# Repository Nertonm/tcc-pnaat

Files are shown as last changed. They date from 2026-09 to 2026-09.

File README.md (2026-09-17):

# PNAAT: inspeção multi-view e rastreabilidade em linha de envase

Sistema de inspeção para bancada de envase de garrafas PET. O repositório contém firmware, ponte serial,
serviço de captura, gateway HTTP, inferência, registro SQLite, dashboard, cadeia de treino e CAD. A ponte
em `src-production/firmware/esp32cam-test/esp32cam_site.py` é dona das portas seriais e encaminha o trigger à câmera;
`api.py` integra as superfícies do rig e da ponte por `PNAAT_RIG` e `PNAAT_PONTE`.

O manual descreve as rotas e os contratos reais. O ponto de entrada técnico é
`docs/operacao-pipeline.md`: ele separa a ponte serial, o serviço de rig, a inferência por diretório e
a ingestão persistida. A topologia e os endereços do runtime são dados de instalação, não valores
versionados.

O núcleo não controla a velocidade da esteira, não atua sobre o item, não promete acurácia sem
medição e não aprova item com evidência ausente. Atuação física, iluminação pulsada, encoder e MQTT
com múltiplos nós são expansão (`docs/escopo.md`).

## Sumário

- [1. Artefatos da entrega](#1-artefatos-da-entrega)
- [2. Rotas de execução](#2-rotas-de-execução)
- [3. Hardware e montagem](#3-hardware-e-montagem)
- [4. Requisitos de software](#4-requisitos-de-software)
- [5. Instalação passo a passo](#5-instalação-passo-a-passo)
- [6. Operar as rotas existentes](#6-operar-as-rotas-existentes)
- [7. Dataset, modelos e CAD](#7-dataset-modelos-e-cad)
- [8. Treinar o detector do zero](#8-treinar-o-detector-do-zero)
- [9. Verificação e reprodutibilidade](#9-verificação-e-reprodutibilidade)
- [10. Estrutura do repositório](#10-estrutura-do-repositório)
- [11. Limites conhecidos](#11-limites-conhecidos)
- [12. Convenções](#12-convenções)
- [13. Créditos e licenças](#13-créditos-e-licenças)

## 1. Artefatos da entrega

| Artefato | Onde está | Estado |
|---|---|---|
| Código do produto (API, pipeline, decisão, registro, site) | `src-production/` | suíte automatizada do produto e do firmware |
| PoCs da geração anterior | fontes removidas deste checkout | os READMEs em `docs/pocs/` são histórico, não comandos executáveis |
| Cadeia de treino (dataset, treino, avaliação, calibração, pacote) | `src-production/treino/` | pronta; rodar exige GPU e o acervo externo |
| Modelos CAD do rig | `cad-produto/` | montagem conferida geometricamente, com ressalvas na seção 3 |
| Diagramas de arquitetura | `docs/arquitetura.md`, `docs/diagramas/` | proposta e implementado, lado a lado |
| Manual de replicação | este arquivo, mais `src-production/README.md` e `src-production/treino/README.md` | publicado |
| Documento formal (Levantamento de Requisitos e roteiro do pitch) | `latex-workspace/` | fonte publicada; compilar exige LuaLaTeX |
| Pacotes de modelo (7) | [huggingface.co/Nerton/pnaat-modelos](https://huggingface.co/Nerton/pnaat-modelos) | publicado, com peso, contrato e `SHA256SUMS` por pacote |
| Índice dos pesos treinados (158 pesos, 35 famílias) | `models/INDEX.csv` | índice versionado; os pesos são dado e ficam fora do repositório |
| Serviço de rig (captura de três câmeras, série e manifest) | `src-production/rig_service/` | testes com câmera falsa: 24 rotas + 49 bordas |

### 1.1 Conferência da Entrega 6

| Exigência | Evidência versionada | Como conferir |
|---|---|---|
| Código-fonte desenvolvido | `src-production/` | `make -C src-production verificar` |
| Esquemático elétrico | `docs/diagramas/interligacao-eletrica.mmd` e projeto histórico `ESP32S3-Trigger.zip` | pinagem e cautelas na seção 3.1 |
| Diagramas finais de arquitetura | `docs/arquitetura.md` | diagramas proposta e implementada, identificados separadamente |
| Pré-requisitos e recursos | seções 3 e 4 | lista de hardware, toolchains e perfis de software |
| Instalação e dependências | seção 5 | ambiente virtual ou Docker |
| Configuração | seção 5.3 | diretórios, URLs, mapa de câmeras e token |
| Montagem e ligações | seções 3.1 e 3.2 | ligação medida antes de energizar e sequência mecânica |
| Execução | seção 6 | API, inferência, ingestão e firmware |
| Confirmação do resultado | seção 9 | comandos, respostas e resultados esperados |

Esta tabela é um índice de auditoria, não substitui os procedimentos. Caminhos que dependem de
hardware ou modelos externos estão marcados como tal; a rota local sem hardware permanece executável.

## 2. Rotas de execução

O projeto tem uma arquitetura proposta e componentes de código que podem ser executados hoje. A
separação importa para replicar sem inventar integração.

```text
sensor E18 -> nó de trigger MicroPython -> ponte serial (esp32cam_site.py) -> ESP32-CAM
                            |
                  captura materializada (série do rig)
                            |
YOLO por diretório: <capturas>/<item>/<vista>.jpg -> pacote -> decisão -> SQLite

série manifestada: manifest.json + fotos -> artefato .npz legado -> decisão -> SQLite

evento de gatilho: CSV ou API -> SQLite
```

A ponte serial `esp32cam_site.py` é o consumidor do enlace UART: decodifica frames, comanda a captura
e publica o estado da ponte. O gateway `api.py` liga rig e ponte ao registro. A rota de diretório usa
pacote YOLO; a ingestão de série usa o artefato legado; as duas persistem na mesma base.

O guia com layout de arquivos, comandos, contratos, efeitos no banco e limites está em
`docs/operacao-pipeline.md`. A replicação do zero, com firmware, serviços e verificação, está em
`docs/replicacao-ponta-a-ponta.md`. A arquitetura proposta e a arquitetura implementada, separadas uma da
outra, estão em `docs/arquitetura.md`.

## 3. Hardware e montagem

A especificação completa, com números de catálogo, pinagem, montagem e o que não foi medido, está em
`docs/hardware.md`. O resumo do que a arquitetura assume:

| Componente | Papel | Estado |
|---|---|---|
| Raspberry Pi 5 | nó de visão: captura, inferência, registro e dashboard | adotado (D-19) |
| ESP32-CAM (AI-Thinker) | nó de visão: uma foto por disparo (via `CMD_TRIG`), câmera em standby entre fotos | firmware implementado e exercitado na bancada |
| Câmeras: CSI, webcam USB e ESP32-CAM | vistas do mesmo item | papéis no `mapeamento-rig.json`, que é dado da instalação |
| Sensor fotoelétrico E18-D80NK | gatilho de presença no nó MicroPython (GPIO27, active-low); a ESP32-CAM também declara GPIO13 como fonte interna | ligação elétrica não medida |
| Impressora 3D | pórtico, suportes de câmera e cases em PETG | peças em `cad-produto/` |

O mapa de câmeras para vistas é: `lateral1` vem da ESP32-CAM, `lateral2` da webcam USB e `topo` da
câmera CSI apontada para baixo (`cad-produto/00-produto/composicao-esteira/contract.json`). Trocar
esse mapa muda a decisão do item, por isso ele é declarado e não inferido.

O esquemático normativo está em `docs/diagramas/interligacao-eletrica.mmd`. O
`ESP32S3-Trigger.zip` da raiz preserva a referência histórica Wokwi, mas usa um PIR genérico e não
fecha a ligação ao GPIO27; não deve ser usado sozinho para montar a bancada.
O firmware declara o pino e o modo elétrico esperado, e o documento de hardware marca a ligação como
não validada até a medição de bancada.

O CAD está em `cad-produto/`: a montagem em `00-produto/composicao-esteira`, as 21 peças do pórtico
em `01-estrutura/`, as peças de impressão em `02-impressao/`, o inventário com SHA-256 em
`cad-produto/MANIFEST.json` e os créditos de terceiros em `cad-produto/ATRIBUICOES.md`. A conferência
foi geométrica, com resíduo de interferência não nulo nos pares da case, abaixo do limite declarado
de 0,1 mm³. Não houve cálculo estrutural, análise térmica nem liberação metrológica.

Conjectura CAD da montagem (peças referência, não desenho de fabricação):

| Imagem | O que mostra |
|---|---|
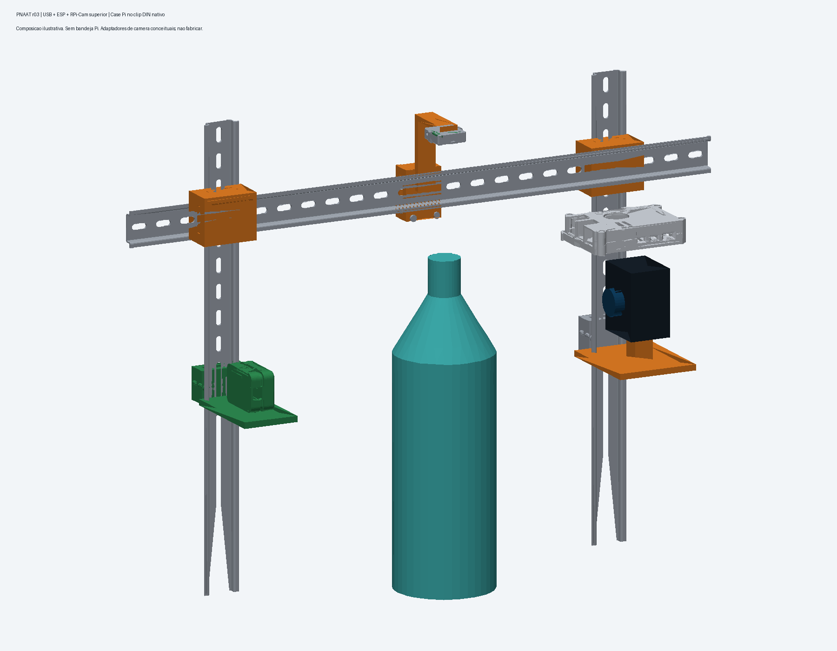
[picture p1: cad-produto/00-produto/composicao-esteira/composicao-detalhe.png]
Detalhe das câmeras e da case
|  | detalhe das três câmeras e da case da Raspberry Pi no trilho |
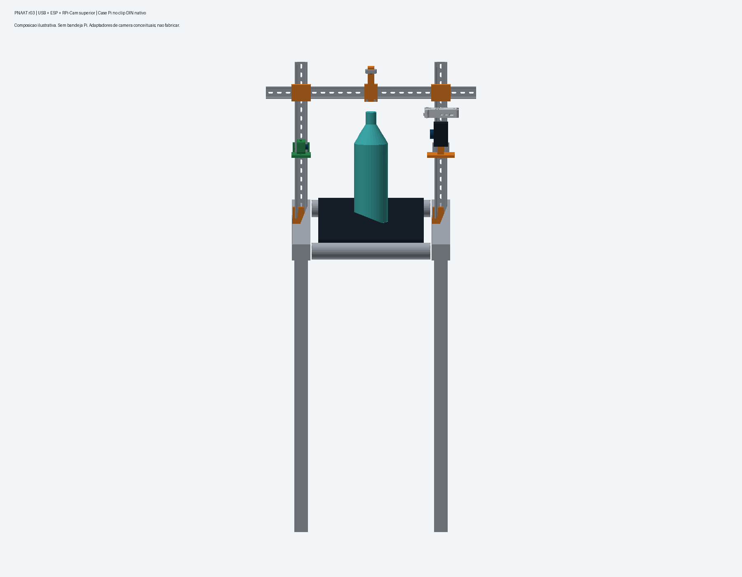
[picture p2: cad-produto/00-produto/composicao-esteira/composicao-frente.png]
Vista frontal da montagem
|  | vista frontal do conjunto |
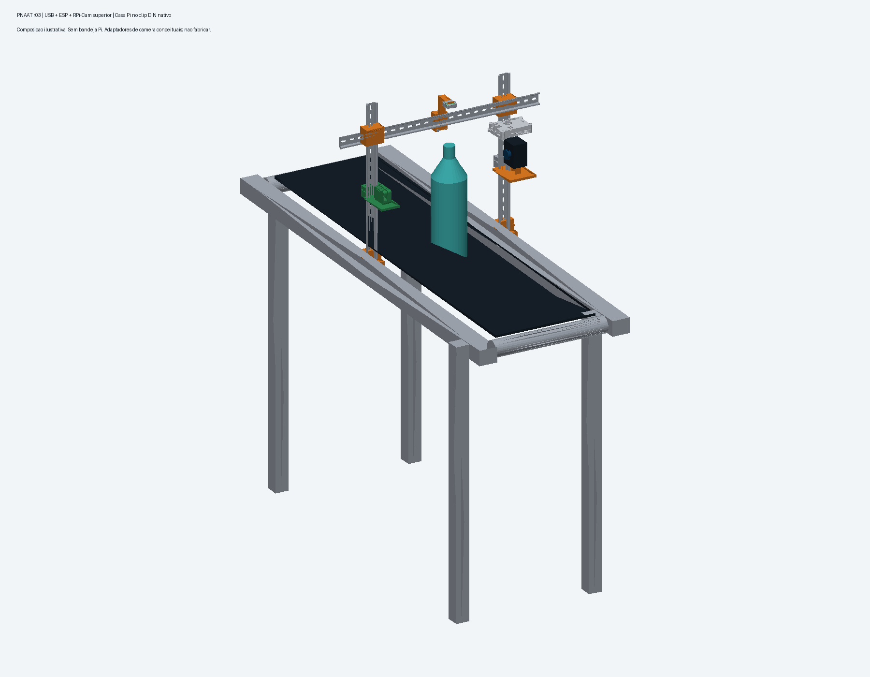
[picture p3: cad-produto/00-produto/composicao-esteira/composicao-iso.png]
Vista isolada do conjunto
|  | vista isométrica da esteira com o pórtico e as câmeras |

Os arquivos editáveis estão nos diretórios indicados
em `cad-produto/`.

### 3.1 Ligação elétrica do trigger

> **Não conecte o fio de sinal ao ESP32 antes de medir a tensão.** Desenergize a bancada para mudar
> a fiação e use GND comum. O GPIO do ESP32 aceita no máximo lógica de 3,3 V.

1. Alimente o E18-D80NK em 5 V: fio bege/marrom em `+5V` e azul em `GND`.
2. Com multímetro em tensão contínua, meça o fio preto contra GND com o sensor livre e com uma
   garrafa presente. O sinal deve ser active-low: alto em repouso e próximo de 0 V com objeto.
3. Se o sinal livre nunca passar de 3,3 V (saída open-collector pura), ligue o preto diretamente ao
   `GPIO27`; o firmware habilita o pull-up interno de 3,3 V.
4. Se o sinal livre ficar próximo de 5 V, ligue preto → `R1 2,2 kΩ` → nó do `GPIO27`, e desse nó →
   `R2 3,3 kΩ` → GND. Confirme no nó uma tensão de no máximo 3,3 V antes de conectá-lo ao GPIO.
5. `GPIO26` é apenas uma saída opcional indicadora da janela de captura; não é a ligação da
   ESP32-CAM. O trigger chega à ponte pela serial USB, e a ponte envia `CMD_TRIG` à ESP32-CAM pela
   segunda serial USB.
6. Energize e confira no monitor serial: `EV READY pin=27 out=26`, depois `EV ARMED`; uma passagem
   deve produzir exatamente um par `EV OPEN`/`EV CLOSE`.

O esquemático atualizado é `docs/diagramas/interligacao-eletrica.mmd`. O ZIP Wokwi preservado na
raiz é histórico, usa um PIR genérico e não é a fonte normativa da pinagem. Fotografias, tensão,
distância e 10 passagens com garrafa vazia e cheia devem ser registradas na validação da bancada.

### 3.2 Sequência de montagem mecânica

1. Imprima ou fabrique as peças indicadas por `cad-produto/README.md`; confira dimensões antes de
   usar os furos M6 e não trate a montagem candidata como desenho liberado para fabricação.
2. Monte `MontanteA`, `MontanteB` e `Travessa` no trilho com junções e chavetas; instale a base DIN.
3. Fixe a câmera CSI acima do trilho, eixo óptico para baixo, preservando a folga nominal de
   110,2836 mm até o topo da garrafa; valide novamente a distância para a lente realmente usada.
4. Instale ESP32-CAM e webcam USB em lados opostos, sem obstrução do item e com iluminação constante.
5. Ligue CSI ao conector da Raspberry Pi, webcam à USB e as duas ESPs a adaptadores USB-seriais
   distintos. Identifique as portas estáveis em `/dev/serial/by-id/`.
6. Declare o mapa `espcam=lateral1,usb=lateral2,csi=topo`, capture uma série de teste e confira
   visualmente se cada arquivo corresponde à vista declarada antes de habilitar decisão.

Medidas, peças, ressalvas geométricas e a lista completa de materiais estão em `docs/hardware.md`.

## 4. Requisitos de software

| Item | Uso |
|---|---|
| Python >= 3.11 e < 3.13 | produto, testes e ferramentas |
| Linux | ambiente de desenvolvimento e nó de visão |
| ESP-IDF v5.x | compilar o firmware da ESP32-CAM |
| FreeCAD com Part, Mesh e Import | reconstruir ou conferir o CAD |
| LuaLaTeX, latexmk e biber | compilar o documento formal |
| GPU com `torch` e `ultralytics` | treino e inferência YOLO; não é necessária para API e consultas locais |

`src-production/pyproject.toml` é a fonte das dependências. O runtime base declara `numpy` e
`opencv-python-headless`; os extras são `leitura` (Pillow e SciPy), `serial` (pyserial), `inferencia`
(torch, torchvision, ultralytics, scikit-learn e PyYAML) e `dev` (pytest, pytest-timeout, ruff e
PyYAML). `anomalib` não é um extra declarado neste checkout. Se for necessário para um experimento,
instale-o num ambiente separado e não o trate como pré-requisito do produto.

## 5. Instalação passo a passo

Os comandos saem da raiz do clone. Cada bloco foi rodado nesta entrega e a saída esperada está
indicada.

O Makefile raiz foi reduzido aos alvos do produto: `make install`, `make -C src-production verificar`
e `make -C src-production lint`. Para uma operação local sem
hardware, consulte `docs/operacao-pipeline.md`.

### 5.1 Obter o código

```bash
git clone https://github.com/Nertonm/tcc-pnaat.git && cd tcc-pnaat
```

### 5.2 Ambiente Python

```bash
python3.11 -m venv .venv            # ou: uv venv --seed --python 3.11 .venv
.venv/bin/python -m pip install --upgrade pip
.venv/bin/python -m pip install -e "src-production[dev,leitura,serial]"
```

O venv é único, na raiz do clone (Python >= 3.11 e < 3.13; instale `python3.11`/`python3.12` ou use
`uv`). O `Makefile` de `src-production/` encontra `../.venv/bin/python`.
Para treino e inferência YOLO, acrescente o extra de inferência:

```bash
.venv/bin/python -m pip install -e "src-production[inferencia]"
```

### 5.3 Configurar a instalação

Não há endereço, device ou mapa de câmera pessoal embutido no código. Declare, conforme a rota:

```bash
export PNAAT_SERIES_DIR=/caminho/gravavel/series
export PNAAT_PONTE=http://127.0.0.1:8094
export PNAAT_RIG=http://127.0.0.1:8090
export PNAAT_API_TOKEN='gere-um-token-longo-e-aleatorio'  # obrigatório fora de loopback/Docker
export PNAAT_MODELOS=/caminho/para/pesos-e-datasets       # somente treino/inferência
```

Use `/dev/serial/by-id/...` para `--serial` e `--serial-trigger`; não suponha que `ttyUSB0` seja
sempre a mesma placa. O diretório de séries precisa ser gravável pelo usuário do serviço. O mapa de
vistas não tem default e deve ser informado na ingestão como
`csi=topo,usb=lateral2,espcam=lateral1`. Endereços diferentes são permitidos, desde que as três URLs
sejam alcançáveis pelo gateway.

### 5.4 Verificar a instalação

```bash
make -C src-production verificar     # suíte do produto e do firmware
make -C src-production lint          # ruff com a configuração do projeto
```

A saída esperada não contém falhas, termina com `produto e firmware verificados` e o lint imprime
`All checks passed!`. Skips podem aparecer quando não estão instalados `scikit-learn`, do extra
`inferencia`, ou o artefato `.npz` do classificador, que é dado e vive fora do git. Não se fixa aqui
uma contagem: adicionar um teste correto não deve tornar o manual falso.

### 5.5 Execução conteinerizada

Como alternativa ao ambiente virtual, a composição reproduz a API, o serviço do rig e a ponte em
uma imagem Python 3.11. O perfil completo inclui a inferência e, por isso, o primeiro build pode ser
demorado. Da raiz do clone:

```bash
docker compose -f docker/docker-compose.yml build
export PNAAT_API_TOKEN='troque-este-token'
docker compose -f docker/docker-compose.yml up -d api    # sem hardware: só o núcleo
docker compose -f docker/docker-compose.yml ps
curl -H "Authorization: Bearer $PNAAT_API_TOKEN" http://127.0.0.1:8080/api/health
```

Os serviços `rig` e `ponte` precisam das câmeras e das portas seriais reais; sem o hardware, use
somente a API (`up -d api`); `rig` e `ponte` ficam no profile `hardware`. Antes de expor a porta,
defina um `PNAAT_API_TOKEN` próprio. Os devices, o diretório de séries e todas as variáveis estão documentados em `docker/docker-compose.yml` e em `docs/replicacao-ponta-a-ponta.md`.
Com hardware (câmeras e portas seriais reais), a pilha completa sobe pelo profile `hardware`:

```bash
docker compose --profile hardware -f docker/docker-compose.yml up -d
```

### 5.6 Perfis de ambiente

O runtime cobre a demonstração e a operação. O perfil completo acrescenta o que só o treino e a
detecção de anomalia usam.

| Perfil | Instalação | O que fica disponível |
|---|---|---|
| A, produto e demonstração | `src-production[dev,leitura,serial]` | cobre testes, API e demonstração local |
| B, inferência YOLO | perfil A mais `src-production[inferencia]`, pacote e dados externos | abre o pacote e roda inferência por diretório |

O `doctor` vivia na árvore de PoCs removida deste checkout. Para treino, a localização externa é
`PNAAT_MODELOS`, consumida pelo Makefile de `src-production/`; ela deve conter os datasets montados,
runs, pesos e metadados. O export canônico do Label Studio e os dados brutos não são criados pelo
clone. Veja `dataset/README.md` para a topologia do dado e `src-production/treino/README.md` para os
scripts que o consomem.

## 6. Operar as rotas existentes

O fluxo completo está em `docs/operacao-pipeline.md`. Esta seção é o resumo executável.

### 6.1 Operação local sem hardware

Sem rig, câmera e pacote, a API ainda sobe contra um banco local. Em banco novo, o
`/api/health` inicializa o schema; consulte `docs/dados-telemetria.md` para o contrato das rotas.

```bash
.venv/bin/python src-production/api.py --db hub.db --porta 8080 --host 127.0.0.1
```

Bind fora do loopback exige token. Não existe alvo de demonstração neste checkout; o site e a API
funcionam com os dados que estiverem no banco informado.

### 6.2 Inferência YOLO com imagens já materializadas

O diretório precisa ter `<CAPTURA>/<ITEM>/lateral1.jpg`, `lateral2.jpg` e `topo.jpg`. `CAPTURA` é a
pasta pai do item.

```bash
make -C src-production smoke-detector   PACOTE=/caminho/pacote-detector   CAPTURA=/caminho/capturas   ITEM=ITM-001   DB=/caminho/hub.db   JANELA=0.4   ALINHAMENTO=declarado   EQUIPAMENTO=rig   LOCALIZACAO=bancada
```

O comando valida o pacote, aplica ROI e rotação do contrato, executa a decisão e grava SQLite. Ele
escreve no banco. O classificador YOLO do pacote lateral decide tampa nas laterais; o detector de
topo existe no acervo (`*-topo-detector-roi`, `models/INDEX.csv`) e atua como check dimensional;
CORPO não tem modelo neste pacote e a conformidade mantém o item em `inconclusivo` quando a medida
é exigida.

### 6.3 Ingestão de série manifestada

```bash
.venv/bin/python src-production/ingerir_serie.py   --serie /caminho/serie --lote L1 --db /caminho/hub.db   --roi 0.0 0.0 1.0 1.0   --mapa csi=topo,usb=lateral2,espcam=lateral1   --janela-ms 2000 --alinhamento declarado
```

A série precisa de `manifest.json` e de um mapa câmera para vista. Essa rota registra evidências e usa
o artefato `.npz` legado, não `--pacote-modelo`. Para ligar o trigger físico a ela, ainda é necessário
o serviço de rig apontado por `PNAAT_RIG` (endereço e topologia são da instalação).

### 6.4 Firmware, gatilho e API

O firmware é compilado com ESP-IDF em `src-production/firmware/esp32cam-test/`. CSV e `POST
/api/gatilho` persistem eventos de gatilho, mas não acionam captura nem inferência. A API pode ser
iniciada assim:

```bash
.venv/bin/python src-production/api.py --db hub.db --porta 8080 --host 127.0.0.1
```

Bind fora do loopback exige token. Endereços de rig, ponte serial e adaptador de modelo são dados de
instalação configurados por ambiente e não entram no repositório.

## 7. Dataset, modelos e CAD

O dataset é mantido em `dataset/` e tem guia próprio em `dataset/README.md`. Ele separa captura própria,
anotação humana, dados externos, dados derivados, pares sintéticos e scripts de trabalho. O clone não
contém a entrada canônica `dataset/TRABALHO/anotacoes-ls.csv`, os exports do Label Studio, pesos `.pt`
nem o pacote do detector. Por isso um clone limpo não reproduz treino ou inferência real sem receber
esses insumos.

| Artefato externo | Consumidor | Como é declarado |
|---|---|---|
| export de anotações | `treino/monta_v1_detector.py` | `dataset/TRABALHO/anotacoes-ls.csv` |
| datasets montados, runs e pesos | Makefile de `src-production/` | `PNAAT_MODELOS` |
| pacote YOLO | `orquestracao.py` | `--pacote-modelo` ou `PACOTE=` |
| artefato legado `.npz` | `ingerir_serie.py` | `--modelo` |
| mapa câmera -> vista | ingestão de série | `--mapa` ou `--mapa-arquivo` |

`models/INDEX.csv` é um índice de pesos e hashes; ele não significa que o peso esteja no clone. O CAD
está todo em `cad-produto/`: a montagem de referência, 21 peças estruturais, peças de impressão,
contratos geométricos, `SHA256SUMS` e atribuições. Ele é uma referência geométrica ilustrativa, não
desenho liberado para fabricação. `docs/hardware.md` explica a montagem, a pinagem e o que não foi
medido.

## 8. Treinar o detector do zero

O fluxo de treino é separado da operação e está detalhado em `src-production/treino/README.md`. Ele
consome o export de anotação, monta split por item, valida listas e rótulos, treina, avalia, calibra o
limiar na validação e empacota peso, contrato e metadados. O rotulador assistido usado na criação do
dataset não participa do runtime e sua fonte foi removida
deste checkout; `docs/reference/classificar-gemini.md` preserva o registro histórico.

Com os dados externos e uma GPU disponíveis:

```bash
make -C src-production treino-dataset TAG=v10 VISTA=lateral
make -C src-production treino-run TAG=v10 VISTA=lateral EPOCHS=150 IMGSZ=480
make -C src-production treino-avalia TAG=v10 VISTA=lateral
make -C src-production treino-kfold TAG=v10 VISTA=lateral K=5
```

O pacote de entrega é o elo entre treino e inferência, e os pacotes publicados estão em
[https://huggingface.co/Nerton/pnaat-modelos](https://huggingface.co/Nerton/pnaat-modelos). O alvo `make pacote` roda em dry-run por padrão;
use `--apply` somente depois de revisar o conteúdo e apontar `PACOTE` para um diretório externo. Em
seguida, confirme o pacote já gravado:

```bash
.venv/bin/python src-production/treino/gera_contrato_preproc.py --conferir
.venv/bin/python src-production/treino/pacote_entrega.py --pacote /caminho/pacote
```

O dataset atual basta para demonstração de conceito não para afirmar desempenho operacional.

## 9. Verificação e reprodutibilidade

| Verificação | Comando | O que ela cobre |
|---|---|---|
| Produto e firmware | `make -C src-production verificar` | decisão, registro, API, cadeia, pacote, documentação e transporte; termina sem falhas |
| Lint | `make -C src-production lint` | zero achado com a configuração do `pyproject.toml` |
| Contrato do detector | `treino/gera_contrato_preproc.py --conferir` | ROI, limiares, classes, imgsz, fingerprint e SHA-256 do peso, pelo validador do consumidor |
| Pacote do detector | `treino/pacote_entrega.py --pacote <dir>` | read-back fechado de um pacote já gravado |

Nenhum número deste repositório é afirmação solta. Os pesos e o artefato do classificador são dado
com SHA-256 registrado, em `models/INDEX.csv` e em `src-production/README.md`, e cada número tem o
script que o recomputa. O caminho completo está em `src-production/README.md`, na seção "Reproduzir o
número de capa".

O que não dá para verificar sem os dados nem a instalação: acurácia do detector, medição elétrica do
sensor e desempenho no Pi 5 em operação contínua. Esses itens estão na seção 11 e em `docs/hardware.md`.

## 10. Estrutura do repositório

```text
tcc-pnaat/
├── README.md              Este manual
├── Makefile               Atalhos: install, verificar, lint
├── CONTRIBUTING.md        Convenções de contribuição e de commit
├── src-production/        O produto: API, pipeline, decisão, registro, site, firmware e treino
│   ├── treino/            Cadeia de treino, do dataset ao pacote
│   ├── firmware/          Firmware ESP32-CAM e receptor do transporte binário
│   ├── site/              Frontend estático, servido pela API
│   └── tests/             suíte automatizada do produto
├── cad-produto/           CAD do rig: montagem, 21 peças, peças de impressão, créditos e SHA256SUMS
├── docs/                  Guia de operação, arquitetura, hardware, requisitos, decisões e referências
├── dataset/               Amostras de método, 181 arquivos
├── models/                Índice dos pesos e pacotes publicados no Hugging Face
├── latex-workspace/       Documento formal e roteiro do pitch
```

A organização por namespace está descrita acima; a política de mídia e o que entra no histórico seguem o `.gitignore` e o gate de revisão do diff.

## 11. Limites conhecidos

1. O acionamento do E18-D80NK está no nó MicroPython de trigger (`src-production/firmware/trigger-node/esp/main.py`,
   GPIO27) e no contrato da ESP32-CAM (GPIO13). Níveis elétricos do sensor real não foram medidos; o
   fluxo foi exercitado por comando de bancada, simulador e portas da ponte.
2. A ponte serial em `src-production/firmware/esp32cam-test/esp32cam_site.py` recebe o trigger,
   comanda a câmera e publica o estado do enlace. O gateway `api.py` encaminha as rotas do rig e da
   ponte. Captura, ingestão e inferência usam contratos próprios; `docs/operacao-pipeline.md` descreve
   onde cada serviço entra e que dados persistem.
3. O número do modelo de tampa, 0,977 de acurácia com Wilson 0,882, vem do conjunto próprio, que
   conta as imagens de deformidade como `normal` no domínio da tampa. O mapeamento é deliberado e
   está em `src-production/README.md`.
4. O valor do limiar por classe não entra na impressão digital do contrato. Só ROI, rotação,
   orientação, imgsz, classes, vista e o SHA do peso são cobertos, então editar o número mantendo
   `fonte` e `calibrado` passa na validação estrutural. É lacuna conhecida, registrada no README do
   produto.
5. O CAD tem conferência geométrica e nada além disso: sem cálculo estrutural, térmico ou liberação
   metrológica.
6. Firmware, CAD e documento formal dependem de toolchains externas, ESP-IDF, FreeCAD e LuaLaTeX.
   Sem elas, os respectivos alvos param com erro declarado.

## 12. Convenções

Documentação e comentários em português, com nomes de código sem acento. Cada PoC tem README próprio,
e cada decisão entra em `docs/DECISIONS.md` com critério de fechamento.

A árvore de PoCs e seu gate de commit foram removidos deste checkout. Antes de publicar, rode a
validação disponível no produto e revise o diff de modo explícito:

```bash
make -C src-production verificar
make -C src-production lint
git diff --check
```

Um commit, uma intenção. Nunca `git add -A`, e mídia não entra no histórico. A evidência segue a
cadeia física, dado, modelo, teste e documentação (D-16), então número sem medição não entra no
texto.

## 13. Créditos e licenças

O CAD de terceiros tem crédito, fonte e licença por arquivo em `cad-produto/ATRIBUICOES.md`: o
Raspberry Pi 5 Din Rail, de Diyalec, em CC BY-SA; o DIN Rail Bracket for M6 Bolts, de ADSRMedia, em
CC BY-NC-SA 4.0; e o Raspberry Pi 4B case with RPi camera 2 arm, de Dominik Chuchlík, em CC BY 4.0.
Os modelos oficiais da Raspberry Pi e os desenhos mecânicos estão em
`cad-produto/03-referencias/freecad/`.

Os datasets públicos usados como apoio metodológico, MVTec e Roboflow, estão em
`docs/reference/datasets-externos-roboflow.md` e em `docs/reference/`. As referências técnicas com
grau de verificação estão em `docs/REFERENCIAS.md`.

As bibliotecas usadas são NumPy, OpenCV, SciPy, Pillow e pyserial no runtime; PyTorch, torchvision,
Ultralytics e scikit-learn no treino e na inferência; e Anomalib na camada de expansão. Cada uma
mantém a licença do próprio projeto. O documento formal está em `latex-workspace/`.

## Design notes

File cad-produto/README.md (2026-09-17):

# CAD 

Peças e montagem de referência do pórtico de inspeção multi-view de garrafas PET
do TCC. O eixo Z é a altura.

## Imagens

Detalhe das três câmeras e da case da Raspberry Pi no trilho:

Detalhe das câmeras e da case

Vista frontal:

Vista frontal da montagem

Cases de Raspberry Pi avaliadas, lado a lado:

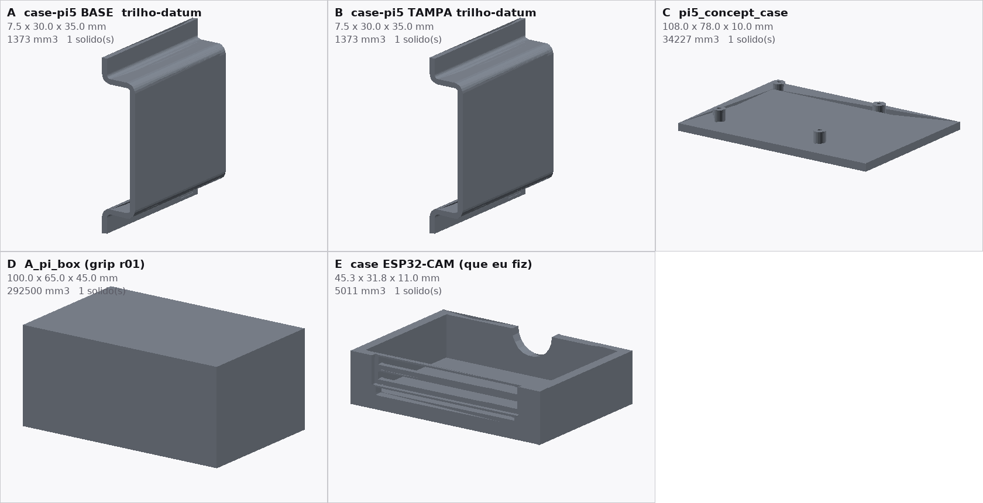
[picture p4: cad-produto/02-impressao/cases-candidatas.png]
Cases avaliadas


## O que tem na pasta

```
00-produto/            montagem e prévias
  composicao-esteira/  revisão r03: modelo, imagens, contrato e verificações
01-estrutura/          as 21 peças do pórtico, separadas
02-impressao/
  base-trilho/         base de chão do trilho
  camera-lateral/      suporte lateral da câmera
  case-esp32cam/       case da ESP32-CAM
  case-pi-din/         case da Raspberry Pi 5 para trilho DIN
03-referencias/        modelos de referência
ATRIBUICOES.md         autor, fonte e licença de cada modelo de terceiro
MANIFEST.json          inventário por arquivo, com origem, bytes e SHA-256
SHA256SUMS             conferência de integridade
```

### 00-produto

| arquivo | conteúdo |
|---|---|
| `00-produto/composicao-esteira/composicao.stl` | montagem completa, 51 corpos |
| `00-produto/composicao-esteira/composicao-iso.png` | vista geral |
| `00-produto/composicao-esteira/composicao-detalhe.png` | detalhe das câmeras e da case |
| `00-produto/composicao-esteira/composicao-frente.png` | vista frontal |
| `00-produto/composicao-esteira/contract.json` | referencial e conteúdo da montagem |
| `00-produto/composicao-esteira/build.py` | script que monta o conjunto |
| `00-produto/composicao-esteira/verify.py` | script que confere o conjunto |
| `00-produto/composicao-esteira/verification-build.json` | conferências feitas na montagem |
| `00-produto/composicao-esteira/verification-readback.json` | conferências feitas na reabertura |
| `00-produto/conjunto-portico.stl` | só a estrutura do pórtico |
| `00-produto/completo-iso.png` | cópia de `00-produto/composicao-esteira/composicao-iso.png` |
| `00-produto/completo-frente.png` | cópia de `00-produto/composicao-esteira/composicao-frente.png` |
| `00-produto/case-no-trilho-closeup.png` | cópia de `00-produto/composicao-esteira/composicao-detalhe.png` |

### 01-estrutura

As 21 peças do pórtico em `.stl`, uma por arquivo: MontanteA e MontanteB,
Travessa, JuncaoA e JuncaoB, ChavetaA e ChavetaB, A_BRACKET, B_BRACKET,
A_CLAMP, B_CLAMP, A_PECA, B_PECA, ClampFunctionalSource e ClampFunctionalSourceB,
PecaDuplaPlataformasOFICIAL e PecaDuplaPlataformasOFICIALB, ParafusoTravaH_A e
ParafusoTravaH_B, ParafusoTravaV_A e ParafusoTravaV_B.

### 02-impressao

| pasta | conteúdo |
|---|---|
| `base-trilho/` | base que recebe a peça do bracket já impressa, com furo passante para parafuso M6, em `.stl` e `.step`, mais a documentação da peça |
| `camera-lateral/` | suporte lateral em seis peças, em `.stl` e `.step`, com as duas peças de origem de terceiro marcadas no nome do arquivo |
| `case-esp32cam/` | case da ESP32-CAM para trilho DIN, em `.step` |
| `case-pi-din/` | case da Raspberry Pi 5 para trilho DIN, em `.stl`, com o desenho do autor e os arquivos de licença |
| `02-impressao/cases-candidatas.png` | comparação entre as cases avaliadas |

### 03-referencias

Modelos oficiais da Raspberry Pi e desenhos mecânicos, com README próprio na
subpasta `freecad/`.

## O que foi feito

Montagem de referência com esteira de exemplo, pórtico de dois montantes DIN,
travessa e três câmeras.

A case da Raspberry Pi entra pelo encaixe de trilho que a própria peça já tem,
sem bandeja e sem suporte extra. O encaixe foi localizado na lateral da peça de
origem e a case é posicionada com um giro de um quarto de volta em Z.

As câmeras ficaram assim: uma no topo, voltada para baixo e sobre a esteira; uma
webcam USB em uma lateral; uma ESP-CAM na lateral oposta.

As 21 peças do pórtico foram separadas em `01-estrutura/`.

A base de chão do trilho recebe a peça do bracket já impressa, leva um parafuso
passante M6 e quatro furos de fixação. A posição do furo veio da medição do
conjunto M6 em posição de uso, não de suposição.

A case da ESP32-CAM foi desenhada a partir das medidas de catálogo do módulo
AI-Thinker.

Os arquivos exportados foram reabertos e conferidos. As medidas exatas estão em
`00-produto/composicao-esteira/verification-build.json` e
`00-produto/composicao-esteira/verification-readback.json`.

## Conferências

Foram conferidos o número de corpos, sólidos e triângulos, o tamanho do conjunto,
o apontamento da câmera de topo, a folga dela até a garrafa e o encaixe da case
no trilho. Os pares testados não passaram do limite declarado de 0,1 mm³; a case tem resíduos não nulos de interferência registrados nos JSONs de verificação.

O encaixe da case foi medido com controle: empurrar a case para dentro ou para
fora faz o teste acusar colisão, e afastar a peça faz o teste acusar zero. Isso
mostra que o teste detecta penetração, e não que a case esteja travada.

As conferências são geométricas. Não cobrem carga, vibração, fadiga, retenção do
encaixe, foco, campo de visão nem impressão.

## Referências e créditos

A lista completa, com autor, fonte, licença e onde cada modelo foi usado, está
em `ATRIBUICOES.md`. Cada licença foi lida do arquivo que veio no próprio
download.

Três modelos de terceiro entraram no produto:

| modelo | autor | fonte | licença | onde |
|---|---|---|---|---|
| Raspberry Pi 5 Din Rail | Diyalec | Thingiverse 6335141 | CC BY-SA | case da Pi |
| DIN Rail Bracket for M6 Bolts | ADSRMedia | Printables 573570 | CC BY-NC-SA 4.0 | base do trilho |
| Raspberry Pi 4B case with RPi camera 2 arm | Dominik Chuchlík | Printables 301598 | CC BY 4.0 | suporte lateral |

O pórtico, os trilhos e a case da ESP32-CAM são geração própria do projeto.
Modelos oficiais da Raspberry Pi e desenhos mecânicos em `03-referencias/freecad/`,
que também descreve o que existe em `03-referencias/vendor/`.

## Observações

Este diretório não contém desenho de fabricação. A montagem serve para discutir
arquitetura e enquadramento das câmeras, e não passou por cálculo estrutural,
análise térmica ou liberação metrológica.

Os colares, braços e bandejas das câmeras são propostas conceituais, destacadas
em laranja nas prévias.

A webcam USB é genérica por decisão do projeto, para mostrar que a arquitetura
aceita câmeras diferentes. Isso não significa que qualquer webcam encaixe nem
que o software a suporte.

As montagens estão em `.stl` apenas. Os arquivos editáveis (`.step` e `.FCStd`)
não estão neste diretório.

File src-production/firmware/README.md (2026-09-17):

# Firmware do nó de visão e do nó de trigger

O produto carrega dois nós de firmware, ambos com o código no repositório:

| Nó | Caminho | Papel |
|---|---|---|
| Visão (ESP32-CAM) | `esp32cam-test/` | uma foto por trigger, câmera em standby entre fotos, transporte binário enquadrado; receptor `esp32cam_site.py` é dono único da porta serial |
| Trigger (ESP32 + E18-D80NK) | `trigger-node/` | sensor de presença com debounce, arming seguro e guarda anti-duplicação; MicroPython com lane de host |

A integração de ponta a ponta tem código nesta árvore: o sensor dispara o nó de trigger, a ponte
`esp32cam_site.py` recebe o enlace e comanda o nó de visão, e o gateway `api.py` conecta rig e ponte
ao registro. O que permanece configuração de instalação são os endereços (`PNAAT_RIG`, `PNAAT_PONTE`)
e a topologia das portas; não é código ausente.

## Objetivo do nó de visão

A ESP32-CAM deve cumprir somente estas responsabilidades:

1. observar o sensor de presença/trigger;
2. registrar o instante do disparo;
3. acordar a câmera e capturar um JPEG sob demanda;
4. entregar o JPEG e os metadados ao Pi por uma interface confiável;
5. voltar ao estado de baixo consumo após a captura.

O Pi é o dono do pipeline de visão, persistência, decisão e reação operacional. A ESP não deve
classificar defeitos nem decidir aprovação/reprovação.

## Fluxo

```text
sensor -> GPIO/IRQ -> fila FreeRTOS -> tarefa de captura
                                      |
                                      v
                              JPEG + metadados
                                      |
                                      v
                         UART/USB -> receptor no Pi
                                      |
                                      v
                 validação -> item capturado -> visão -> registro
```

A ISR deve ser mínima: timestamp, origem e envio para a fila com `xQueueSendFromISR`. Wake-up,
captura, codificação, transmissão e qualquer I/O ficam em tasks FreeRTOS. Um trigger não deve
executar lógica pesada dentro da ISR.

## Transporte implementado (v1)

Dois modos, alternáveis em runtime por `CMD_TRANSPORT TEXT|BIN`:

- `text`: linhas delimitadas com payload base64, no formato de texto legado;
- `bin`: enquadramento binário, com cabeçalho, payload e CRC por mensagem.

```text
SOF A5 5A | VER | TYPE | FLAGS | EVENT u16 | SEQ u32 | LEN u16 | CRC16(VER..LEN) | payload | CRC32(payload)
TYPE: 1=BEGIN 2=CHUNK 3=END 4=ACK 5=NACK        (tudo little-endian)
BEGIN: payload de 16 B (total_len u32, frame_crc32 u32, trigger_us i64)
CHUNK: payload de até 1024 B                    END: payload de 4 B (frame_crc32)
```

Logs ASCII convivem com as mensagens no mesmo fio: o receptor demuxa por enquadramento
(SOF + CRC16 do cabeçalho) e trata o resto como texto. Não há flag de modo no receptor.

Medido no fio, mesma placa e mesmas condições (frame de ~13 kB):

| modo | bytes na linha | fator sobre o JPEG | tempo na linha |
|---|---|---|---|
| texto base64 @ 921600 | 27.233 | 2,15x | 292 ms |
| binário @ 921600 | 14.921 | 1,13x | 191 ms |
| binário @ 1,5 Mbps | — | — | 145 ms |

Além do bloco binário, o firmware imprime `FRAME_INFO ... len= crc32=` em ASCII: o host recalcula
o CRC-32 do frame montado com `zlib` e compara. Duas implementações independentes concordando
separa erro de enlace de erro de implementação de CRC.

## Contrato congelado

```text
PROTOCOL_VERSION = 1
TRANSPORT = UART_USB (console e imagem no mesmo fio, demux por enquadramento)
TRIGGER_GPIO = 13 (E18-D80NK, active-low, borda de descida)
TRIGGER_ELECTRICAL_MODE = active-low, pull-up interno; níveis do sensor real ainda não medidos
FRAME_ENCODING = binário (texto mantido por compatibilidade)
FRAME_MAX_BYTES = 1024 B por chunk, 4096 B por mensagem, 4 MiB por frame no host
FRAME_TIMEOUT_MS = 25 s por foto no host (declarado no contrato; o enforcement de timeout ainda não está no receptor) (evento completo medido em ~1,4 s)
RETRY_POLICY = fail-closed: frame rejeitado não é publicado e o host tenta uma segunda captura
PERSISTENCE_POLICY = o host serve o último frame válido; o registro canônico é do pipeline do Pi
```

Estados observáveis no fio: `CAMERA_OFF boot=1` e `CAMERA_OFF motivo=fim_da_captura|falha_init|fim_do_teste`,
`STATUS camera=standby|ativa driver=0|1 transport=bin|text baud=`, `SENSOR_TEST pwdn=0|1 detect=`,
`FRAME_INFO`, `FRAME_END_BIN`.

## Energia da câmera

Entre fotos o firmware: desinicializa o driver, assere `PWDN` (standby do sensor), para o XCLK
(`ledc_stop` + pino em entrada com pull-down) e desliga a chave de carga quando ela existe.

Verificado funcionalmente: com `PWDN` alto o sensor **não responde** na detecção, e `STATUS`
reporta `camera=standby driver=0`. Atenção: isso é standby, não corte de 3V3; o módulo segue
alimentado. Corte real exige chave de carga no rail da câmera; o firmware já tem o caminho
pronto em `CAM_POWER_GPIO` (-1 = ausente nesta placa).

Comandos: `CMD_CAPTURE`, `CMD_STATUS`, `CMD_SENSOR` (teste A/B de energia), `CMD_TRANSPORT TEXT|BIN`,
`CMD_BAUD <n>`, `CMD_TEST_FALHA_INIT` (diagnóstico: força a próxima captura a falhar na init).

## Como o Pi recebe

O receptor do Pi deve ser uma única dona lógica da porta serial. Nenhuma thread HTTP deve escrever
diretamente na UART enquanto outra thread lê. Comandos devem entrar em uma fila de comandos, e a
thread responsável pela serial deve serializar leitura e escrita.

Máquina de estados mínima do receptor:

```text
IDLE
  -> HEADER_RECEIVED       ao receber FRAME_BEGIN válido
HEADER_RECEIVED
  -> RECEIVING              ao aceitar o primeiro chunk
  -> IDLE + erro            se header inválido ou timeout
RECEIVING
  -> COMPLETE               ao receber todos os chunks esperados e FRAME_END
  -> IDLE + erro            se seq faltar, duplicar, exceder limite ou timeout
COMPLETE
  -> VALIDATED              após tamanho, JPEG e CRC passarem
VALIDATED
  -> PUBLISHED              somente após disponibilizar uma cópia imutável ao pipeline do Pi
```

Regras obrigatórias no Pi:

1. ao receber `FRAME_BEGIN`, abandonar o frame parcialmente aberto anterior e registrar o motivo;
2. validar versão, origem permitida, `event_id`, tamanho máximo e campos numéricos;
3. aceitar chunks somente do `event_id` atual;
4. exigir sequência contígua, sem lacuna e sem duplicata;
5. aplicar timeout tanto entre chunks quanto para o frame inteiro;
6. limitar memória antes de alocar o payload anunciado;
7. decodificar base64 com validação estrita enquanto o modo texto existir;
8. verificar tamanho real, `FF D8`, `FF D9` e CRC-32 antes de publicar;
9. publicar o frame somente depois de todas as validações;
10. preservar `event_id`, origem, timestamp, métricas e motivo de falha;
11. nunca substituir silenciosamente um frame válido por um frame parcial ou antigo;
12. responder `ACK` apenas após validação e `NACK` com motivo fechado quando rejeitar (regra declarada; o receptor atual ainda não emite ACK/NACK, o descarte é pelo CRC/fechamento).

O estado `latest frame` é uma conveniência de visualização, não o registro canônico. O Pi deve
persistir ou encaminhar o evento de forma idempotente, usando `event_id` e a identidade do rig.

Receptor implementado: `esp32cam-test/transport_bin.py` (decoder + montador com os gates) e
`esp32cam-test/esp32cam_site.py` (dona única da porta, site de captura). Testes em
`esp32cam-test/tests/test_transport_bin.py`.

## Como o Pi deve reagir

Para `source=e18_d80nk` e frame validado:

1. registrar o evento de trigger, mesmo que a captura falhe;
2. associar o JPEG ao evento e gerar o `item_id` no lado do Pi;
3. verificar timestamp e janela temporal do rig;
4. validar legibilidade, resolução e enquadramento;
5. encaminhar a imagem para o pipeline de visão;
6. executar classificação por vista e fusão por domínio;
7. registrar decisão, confiança, evidências, hash do JPEG e métricas;
8. responder ao operador com `normal`, `defeito` ou `inconclusivo` conforme as regras do pipeline.

Reações fail-closed:

- trigger sem JPEG: registrar `inconclusivo` ou evento sem captura, nunca fingir normalidade;
- JPEG inválido/CRC incorreto: descartar como evidência, registrar `frame_invalido`;
- timeout: registrar `timeout_captura` com `event_id`;
- evento duplicado: não gerar segundo item; registrar duplicata;
- origem `usb_command`: aceitar somente em modo de bancada explicitamente habilitado;
- timestamp fora da janela: preservar a imagem, mas marcar `timestamp_divergente`;
- qualidade insuficiente: não enviar para decisão como se fosse evidência adequada;
- falha do modelo ou do registro: manter o evento e retornar `inconclusivo`.

## Trigger e pinos

A ESP32-CAM oferece GPIO13 active-low como fonte **local alternativa**, mas esse pino fica sem fio na
topologia adotada. O E18-D80NK liga ao nó de trigger dedicado (MicroPython), que usa
`PRESENCE_PIN = 27` e `CAPTURE_OUT_PIN = 26`; o evento segue pela serial USB até a ponte, que envia
`CMD_TRIG` à câmera. Só use divisor de nível se a saída livre do sensor for medida próxima de 5 V;
uma saída open-collector pura usa o pull-up de 3,3 V.

O sensor E18-D80NK é saída digital aberta (NPN): LOW = objeto dentro do alcance. Alimentação 5V;
verifique a tensão real na saída antes de ligar direto ao GPIO. GND comum entre sensor, ESP32 e host
é obrigatório. GPIO4 foi usado apenas num experimento de bancada e não faz parte do trigger.

## Critérios de aceite da integração

Verificados nesta bancada:

- [x] `PWDN` confirmado funcionalmente: `PWDN` alto → sensor não responde (`SENSOR_TEST pwdn=1 detect=0`);
- [x] uma foto por trigger: 3 triggers → exatamente 3 fotos; nenhuma foto em 15 s de ociosidade;
- [x] JPEG válido com tamanho, sequência e CRC conferidos (CRC do firmware x `zlib` no host = ok);
- [x] frame parcial ou corrompido nunca é publicado (CRC por mensagem, CRC do frame, tamanho e
      marcadores `FF D8`/`FF D9`); lacuna de chunk bloqueia o frame e é registrada;
- [x] standby em todos os caminhos (fim de captura, falha de init e fim do teste de energia);
- [x] timeout, duplicata e CRC inválido observáveis no host (contadores e eventos).

Pendentes:

- [ ] níveis elétricos do sensor de presença real e trigger físico medido (hoje só comando de bancada);
- [ ] debounce (50 ms) e cooldown (250 ms) medidos com o E18-D80NK;
- [ ] origem não autorizada: o firmware aceita o comando de bancada sempre; falta gate de modo;
- [ ] corrente e temperatura em idle, wake e captura (não medidos; exige instrumentação);
- [ ] o Pi registrar evento sem captura e captura sem decisão (integração com o pipeline);
- [ ] idempotência de item duplicado no registro canônico;
- [ ] canário em deployment persistente (hoje roda em sessão `tmux`, não como serviço).

## Referências do scaffold

- `esp32cam-test/main/main.c`: firmware (IRQ na fila, uma foto por trigger, standby, transporte);
- `esp32cam-test/transport_bin.py`: contrato binário e receptor (decoder + montador com gates);
- `esp32cam-test/tests/test_transport_bin.py`: testes do transporte (oráculo diferencial e gates);
- `esp32cam-test/esp32cam_site.py`: site de captura; dona única da porta serial;
- `esp32cam-test/usb_stream_bridge.py`: bridge antiga de visualização local, superada pelo site;
- componente `esp32-camera` (v2.1.7): restaurado pelo gerenciador de componentes do ESP-IDF a partir
  de `idf_component.yml` + `dependencies.lock`; nao e versionado.

## Nó de trigger (Sensor E18-D80NK + ESP32 MicroPython)

Portado do canônico para o produto em `trigger-node/`: `esp/main.py` (firmware), `presence.py`
(lógica pura testada), `host/` (supervisor da porta serial, escopo, harness, watch, esp_tool e
simulador) e `tests/test_trigger.py`.

```bash
make -C src-production test-trigger       # lógica pura (5 testes)
make -C src-production trigger-simular    # simulador do debounce básico, sem hardware
PYTHONPATH=src-production/firmware/trigger-node .venv/bin/python \
  src-production/firmware/trigger-node/host/poc01_teste.py --passagens 10 --espera 6 --separacao 3
```

Pinos adotados no `esp/main.py`: `PRESENCE_PIN = 27`, `CAPTURE_OUT_PIN = 26`. A montagem e a medição
obrigatória estão em `trigger-node/esp/README.md`. GPIO27 é a fonte normativa do código atual; isso
não equivale a afirmar que níveis e condicionamento do sensor físico já foram validados.

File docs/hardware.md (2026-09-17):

# Hardware, montagem e ligação

Manual de bancada do PNAAT. Diz o que o sistema usa, como o rig é montado, o que está ligado e
medido, o que está projetado e o que não foi medido. Cada afirmação traz a fonte no repositório; o
que não tem fonte aparece declarado como tal.

Estados usados neste documento: implementado (existe e foi exercitado), projetado (desenho aprovado,
sem bancada) e não medido (sem instrumentação no rig).

## 1. Lista de materiais

| # | Item | Especificação (fonte) | Papel no sistema | Estado |
|---|---|---|---|---|
| 1 | Raspberry Pi 5 | a instalação medida usa cartão de 119 GiB (`mmcblk0`); o repositório recomenda SSD ou NVMe para armazenamento (`docs/DECISIONS.md:1241-1247`) | nó de visão: captura, inferência, registro SQLite e dashboard | adotado (D-19) |
| 2 | ESP32-CAM | módulo AI-Thinker (`src-production/firmware/esp32cam-test/main/main.c:28`; `cad-produto/README.md:96-97`) | uma foto por disparo, câmera em standby entre fotos | implementado |
| 3 | ESP32 com MicroPython | nó de trigger separado, alimentado pelo USB do Pi (`docs/DECISIONS.md:1141`) | lê o sensor de presença e abre a janela de captura | implementado (PoC-01) |
| 4 | Sensor fotoelétrico E18-D80NK | 5 V, saída NPN, alcance de 3 a 80 cm; rótulo 5 VDC e 100 mA, fios bege, preto e azul, cerca de 5 V livre e 0 V com objeto (`docs/reference/ref-e18-d80nk-sensor.md:11-16,24-27`) | gatilho de presença do item | não medido com o sensor real |
| 5 | Adaptadores USB-serial | CP2102 ou CH340, portas resolvidas por `by-id` (`docs/DECISIONS.md:852,983,1149`) | ligam trigger e câmera ao Pi, em duas portas na mesma ponte | implementado |
| 6 | Câmeras | `topo` é a câmera CSI da Raspberry Pi apontada para baixo; `lateral1` é a ESP32-CAM; `lateral2` é a webcam USB UVC (`cad-produto/00-produto/composicao-esteira/contract.json`; `README.md:104`) | vistas do mesmo item | papéis definidos, e são dado da instalação |
| 7 | Cabo flat | FFC de 200 mm (`cad-produto/ATRIBUICOES.md:55`) | liga a câmera CSI à placa | |
| 8 | Trilho DIN e peças impressas | ver seção 3 | estrutura do rig | conferida geometricamente, com ressalvas na seção 3 |
| 9 | Encoder incremental KY-040 | candidato; não faz parte do implementado (`docs/DECISIONS.md:284,307-311`; `docs/arquitetura.md`, seção de expansões) | medição de movimento, na expansão | projetado (expansão) |
| 10 | Esteira | teto derivado de cerca de 107 mm/s, com passo de 80 mm e três vistas; o valor de operação segue a decidir e não medido (`docs/DECISIONS.md:610-616`, `docs/pocs/03-sincronizacao-fisica/CALIBRACAO-DELAY.md:60-64`) | movimento do item; o sistema não controla a esteira | fora do núcleo |
| 11 | Ferragens do trilho | furo passante Ø6,5 para M6, escareado Ø13×1,0, arruela Ø12, quatro furos Ø4,5 com rebaixo Ø9,0×5,0 (`cad-produto/02-impressao/base-trilho/README.md:12-19`) | fixação da base do trilho | medido |

As peças impressas estão em `cad-produto/02-impressao/`. A base do trilho é a única com números de
impressão publicados: um sólido, 241.237,2 mm³, 306,4 g, área de apoio de 11.952,0 mm² e envelope de
131,00 por 103,50 por 36,50 mm, dentro da K1C de 220 por 220 por 250 mm
(`cad-produto/02-impressao/base-trilho/README.md:21-22`, `DOCUMENTACAO-20260914.md:100`). O suporte
lateral da câmera tem 6 peças, o case da ESP32-CAM existe só em `.step`, sem STL
(`cad-produto/README.md:69`), e o case da Raspberry Pi 5 usa o encaixe de trilho DIN da própria
peça. Créditos e licenças de terceiros estão em `cad-produto/ATRIBUICOES.md`.

## 2. Pinagem e interfaces

Estas são as constantes de pino do firmware próprio, em
`src-production/firmware/esp32cam-test/main/main.c`:

| Sinal | Pino (GPIO) | Estado |
|---|---|---|
| Sensor de presença, `SENSOR_GPIO` | 13, active-low, borda de descida, pull-up interno (`main.c:21,702,704`) | declarado; níveis do sensor real não medidos |
| `PWDN` do sensor de imagem | 32, alto coloca o sensor em standby (`main.c:29,110,563`) | verificado na bancada |
| `XCLK` | 0, parado no standby com `ledc_stop` e pino em entrada com pull-down (`main.c:44,78-90,319`) | verificado |
| `SIOD` e `SIOC`, I²C da câmera | 26 e 27 (`main.c:45-46`) | implementado |
| `D0` a `D7`, barramento de dados | 5, 18, 19, 21, 36, 39, 34 e 35 (`main.c:47-54`) | implementado |
| `VSYNC`, `HREF` e `PCLK` | 25, 23 e 22 (`main.c:55-57`) | implementado |
| Chave de carga do rail 3V3 da câmera, `CAM_POWER_GPIO` | -1, ausente nesta placa; o firmware tem o caminho pronto (`main.c:38`) | não implementado no hardware |
| `RESET` da câmera, `CAM_PIN_RESET` | -1, não usado (`main.c:43`) | |
| Comunicação ESP32 e host | UART/USB, console e imagem no mesmo fio, demux por enquadramento com SOF `A5 5A`, CRC16 do cabeçalho e CRC32 do payload | medido no fio |
| Nó de trigger MicroPython (E18-D80NK) | `PRESENCE_PIN=27` active-low com pull-up e `CAPTURE_OUT_PIN=26`, declarados em `firmware/trigger-node/esp/main.py` | lógica implementada; ligação e níveis do sensor real a medir |

O contrato congelado em `src-production/firmware/README.md:78-88` declara apenas `TRIGGER_GPIO`, o
pino 13, e o modo elétrico esperado. Os outros pinos estão no firmware, não no contrato.

`GPIO4` não existe no firmware. Ele aparece uma vez como experimento de bancada em
`src-production/firmware/README.md:185` e não faz parte do trigger de produção.

### Ligação do sensor

O E18-D80NK é alimentado em 5 V e tem saída NPN, do tipo open-collector. A tensão de saída depende
do que existe do lado do módulo, e há dois casos documentados; o que decide entre eles é medição, não
suposição (`docs/reference/ref-e18-d80nk-sensor.md:27,45-49`):

1. Com resistor de pull-up para 5 V no módulo, a saída passa de 3,3 V e exige condicionamento de
   nível, com divisor ou transistor, antes do GPIO.
2. Sem pull-up para 5 V, a entrada pode ser ligada direto usando o `PULL_UP` interno do ESP32.

Nos dois casos, conferir a tensão de saída em bancada antes de ligar. Terra comum entre sensor,
ESP32 e host é obrigatório (`src-production/firmware/README.md:184`).

O esquemático de interligação atualizado está em `docs/diagramas/interligacao-eletrica.mmd`. O
projeto histórico `ESP32S3-Trigger.zip` usa um PIR genérico no Wokwi e **não** é a fonte normativa
da pinagem; sua limitação está registrada em `docs/reference/esquematico-trigger.md`. O firmware
declara GPIO27 e o modo elétrico. Falta medir, com o sensor real, os níveis de saída, o debounce, com
alvo de 50 ms, e o cooldown, com alvo de 250 ms (`main.c:23-24`;
`src-production/firmware/README.md:202`).

A montagem óptica do sensor segue o princípio IR difuso do E18-D80NK: posição e angulação são validadas em bancada; difusor e dois LEDs RGB de 5 mm fazem parte da iluminação de bancada (`docs/requisitos/05-hardware-ml.md:23-31`).
Uma alternativa em avaliação é o VL53L0X (`docs/DECISIONS.md:284`).

## 3. Montagem mecânica

As peças e a montagem de referência estão em `cad-produto/`, com o eixo Z como altura.

1. Pórtico: dois montantes DIN, `MontanteA` e `MontanteB`, mais `Travessa`, junções e chavetas, num
   total de 21 peças em `cad-produto/01-estrutura/` (`cad-produto/MANIFEST.json`).
2. Base do trilho, em `cad-produto/02-impressao/base-trilho/`: recebe o bracket já impresso, com furo
   passante Ø6,5 medido no conjunto em posição de uso, mais quatro furos de fixação
   (`cad-produto/02-impressao/base-trilho/README.md:12-19,24-31`).
3. Suporte lateral de câmera, em `cad-produto/02-impressao/camera-lateral/`: 6 peças em 12 arquivos
   entre `.stl` e `.step`. Três trazem marca de origem de terceiro no próprio nome
   (`Cover_SOURCE_REFERENCE`, `Housing_SOURCE_REFERENCE` e `Swivel_SOURCE_DERIVATIVE`), e
   `cad-produto/ATRIBUICOES.md:42-43` atribui quatro componentes: housing, tampa, swivel e braço.
4. Cases: `case-esp32cam`, desenhada a partir das medidas de catálogo do módulo e só em `.step`, e
   `case-pi-din`, que usa o encaixe de trilho da própria peça de origem girada um quarto de volta em
   Z. O autor e a licença estão no diretório.
5. Câmeras: uma CSI no topo apontada para baixo, uma webcam USB em uma lateral e uma ESP32-CAM na
   lateral oposta (`cad-produto/README.md:87-88`;
   `cad-produto/00-produto/composicao-esteira/contract.json`).

As conferências feitas e o que elas valem estão em
`cad-produto/00-produto/composicao-esteira/verification-build.json` e
`cad-produto/00-produto/composicao-esteira/verification-readback.json`:

| Medida | Valor |
|---|---|
| Corpos, sólidos STEP e triângulos STL | 51, 57 e 80.212 |
| Envelope do conjunto | 600,0 por 1300,0 por 1302,902 mm |
| Eixo óptico da câmera de topo | `[0, 0, -1]`, com `target_dot` de 1,0 |
| Folga do topo até o topo da garrafa | 110,2836 mm |
| Encaixe da case no trilho, controle | 98,386387 mm³ para dentro, 10,256758 mm³ para fora no gancho e 0 mm³ afastado |
| Interferência residual do par case e trilho | 0,0320589710 mm³ na base e 0,0091627391 mm³ na tampa; o limite declarado é 0,1 mm³ e nenhum par passa dele |
| Erro relativo de volume do STEP | 1,6e-10 |

O CAD não chamou esses resíduos de zero. O README do conjunto diz que eles existem e ficam abaixo do
limite declarado (`cad-produto/00-produto/composicao-esteira/README.md:15-16,27`), e o status do
conjunto é `CANDIDATE_GEOMETRY`, ilustrativo e não liberado para fabricação
(`cad-produto/00-produto/composicao-esteira/verification-build.json:2`; `cad-produto/MANIFEST.json:5`;
`cad-produto/00-produto/composicao-esteira/contract.json:10`).

O teste do encaixe tem controle: empurrar a case acusa colisão e afastar zera. Isso mostra que o teste
detecta penetração, não que a case esteja travada
(`cad-produto/00-produto/composicao-esteira/README.md:19-22`).

As pendências do CAD, registradas: o suporte da câmera de topo é conceitual e não está liberado para
imprimir (`cad-produto/00-produto/composicao-esteira/README.md:34`); PCB e lente são ilustrativos e o
CM3 Wide não foi validado
(`cad-produto/00-produto/composicao-esteira/verification-build.json:51`); a inspeção visual não foi
realizada, por falha do provedor de visão
(`cad-produto/00-produto/composicao-esteira/verification-readback.json:29`,
`cad-produto/00-produto/composicao-esteira/README.md:39`); a compatibilidade física está confirmada
pelo usuário, não medida (`cad-produto/00-produto/composicao-esteira/README.md:22`); e a licença do
modelo da ESP não foi verificada (`cad-produto/00-produto/composicao-esteira/README.md:36`;
`cad-produto/ATRIBUICOES.md:101-110`). Na base do trilho, Y igual a 0 é suposição, o M6 não foi
conferido e o caminho de carga e torque não foi calculado
(`cad-produto/02-impressao/base-trilho/README.md:52-58`). Não há layer height, número de paredes,
infill nem orientação publicados para nenhuma peça.

## 4. Alimentação

A ESP32-CAM é alimentada pela porta USB ou serial. Entre fotos o módulo continua alimentado, e o que o
firmware faz é standby do sensor com `PWDN` alto, não corte de 3V3
(`src-production/firmware/README.md:96-102`). O trigger é um ESP32 separado, alimentado pelo USB do Pi
(`docs/DECISIONS.md:1141`). O sensor trabalha em 5 V com consumo de 100 mA ou mais, pelo rótulo
do componente (`docs/reference/ref-e18-d80nk-sensor.md:11-16`), e o GND é comum entre sensor, ESP32 e
host (`src-production/firmware/README.md:184`).

Corrente e temperatura em idle, wake e captura não foram medidas
(`src-production/firmware/README.md:204`). O repositório não declara modelo de fonte para o Pi; a
instalação segue a alimentação própria da placa.

## 5. Verificação de bancada

| Verificação | Resultado | Origem |
|---|---|---|
| `PWDN` funcional | `SENSOR_TEST pwdn=1 detect=0`: o sensor não responde com PWDN alto | `src-production/firmware/README.md:191` |
| Uma foto por trigger | 3 triggers geram exatamente 3 fotos; nenhuma foto em 15 s de ociosidade | idem |
| Frame íntegro | tamanho, sequência e CRC conferidos, com o CRC do firmware batendo com o `zlib` do host | idem |
| Frame parcial ou corrompido | nunca publicado, por CRC por mensagem, CRC do frame, marcadores `FF D8` e `FF D9` e lacuna de chunk | idem |
| Standby | em todos os caminhos: fim de captura, falha de init e fim do teste de energia | idem |
| Transporte no fio, frame JPEG de cerca de 13 kB | texto base64 com 27.233 bytes na linha em 292 ms; binário com 14.921 bytes em 191 ms; binário a 1,5 Mbps em 145 ms (`src-production/firmware/README.md:66-70`) | medido |
| Baud de operação | firmware arranca em 921600 (`SERIAL_BAUD`, `main.c:22`) com negociação até 1,5 Mbps; medida no fio a 921600 e 1,5 Mbps (`src-production/firmware/README.md:66-70`). O histórico D-40 registra falha a 921600 e operação em 460800 (`docs/DECISIONS.md:848-851`) | medido |
| Latência do enlace serial | cerca de 0,75 s de ponta a ponta (`docs/DECISIONS.md:1257`) | medido |

A parte de software se reproduz com `make -C src-production test-firmware`, que roda 17 testes, e
`make -C src-production verificar`, que roda a suíte do produto mais o firmware.

## 6. Serviços em operação

O rig não roda em sessão de terminal. A operação usa units systemd no Pi
(`docs/DECISIONS.md:911-918,745-747,1043`):

| Unit | Papel |
|---|---|
| `pnaat-ponte.service` | dono das duas portas seriais, trigger e câmera, resolvidas por `by-id` |
| `pnaat-gatilho-posboot.service` | estado do gatilho depois do boot |
| `pnaat-hub-site.service` | site e hub do Pi na porta 8091, usuário `nerton` |

O serviço de captura do rig responde em `127.0.0.1:8090`, configurado por `PNAAT_RIG`; a ponte fica
em `127.0.0.1:8094`, por `PNAAT_PONTE`; e o adaptador de modelo em `127.0.0.1:8093`, por
`PNAAT_MODEL_API` (`src-production/api.py:63-68`). Esse runtime
fica fora do repositório por decisão, porque carrega caminho pessoal, host e a tabela de ROI da
instalação.

## 7. Limites de validação e pendências de bancada

1. O sensor de proximidade E18-D80NK está declarado no firmware e no mapa de GPIO, sem medição
   registrada da ligação física (seção 2).
2. Níveis elétricos do E18-D80NK e ligação física ao GPIO27 do nó de trigger não foram medidos
   (seção 2). O GPIO13 da ESP32-CAM é somente uma entrada local alternativa, sem fio na topologia
   adotada com o nó dedicado.
3. Debounce, com alvo de 50 ms, e cooldown, com alvo de 250 ms, não foram medidos com o sensor real.
4. O firmware aceita comando de bancada de qualquer origem. A restrição por origem em modo de
   produção é um modo de segurança documentado, a ser habilitado na instalação
   (`src-production/firmware/README.md:203`).
5. Corrente e temperatura em idle, wake e captura não foram medidas.
6. A cadeia de trigger tem código no repositório: o nó MicroPython (`firmware/trigger-node/`), a ponte
   serial (`esp32cam_site.py`), o gateway (`api.py`) e o registro idempotente por `item_id`. Níveis
   elétricos do sensor real e latência física seguem como medição de bancada pendente conforme as
   seções 2 e 5; essa pendência é de validação, não de código ausente. O contrato está em
   `docs/operacao-pipeline.md`.
7. O corte de energia da câmera tem o caminho pronto no firmware, em `CAM_POWER_GPIO`, e exige chave de
   carga no rail 3V3; nesta placa o GPIO está ausente.
8. No CAD, o suporte da câmera de topo não está liberado para impressão, a inspeção visual não foi
   feita e a licença do modelo da ESP não foi verificada (seção 3).

## 8. Onde cada assunto é aprofundado

| Assunto | Documento |
|---|---|
| Especificação do produto e do evento | `docs/arquitetura.md` |
| Requisitos de hardware, iluminação e ML | `docs/requisitos/05-hardware-ml.md` |
| Sensor de presença, características e identificação de fios | `docs/reference/ref-e18-d80nk-sensor.md` |
| Decisões D-19, D-20, D-21, D-23 e D-38, e o histórico do baud | `docs/DECISIONS.md` |
| CAD, peças, atribuições e conferências | `cad-produto/README.md`, `cad-produto/ATRIBUICOES.md` e `cad-produto/00-produto/composicao-esteira/README.md` |
| Firmware, contrato congelado, protocolo e critérios de aceite | `src-production/firmware/README.md` |
| Política de mídia e higiene do repositório | ferramenta removida deste checkout; revisar `.gitignore` e o diff antes de publicar |
| Instalação e execução | `README.md` |

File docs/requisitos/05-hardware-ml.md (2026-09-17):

# Hardware, iluminação, ambiente e machine learning

## Hardware e ambiente

### HW-01: Geometria repetível

- Entrada: posições de câmeras, trigger e encoder.
- Critério: montagem repetida mantém enquadramento e calibração dentro da tolerância definida antes do ensaio.
- Critério de reprovação: mover o grip e obter drift sem registro. Evidência: desenho, cotas, calibração antes/depois.

### HW-02: Conexões críticas fixas

- Critério: trigger, encoder e sensores móveis são soldados ou presos em breakout; continuidade passa no multímetro.
- Critério de reprovação: circuito aberto ou jumper solto. Evidência: checklist e medição.

### HW-03: Mounts e jig

- Critério: suportes parafusados e jig posicionam item repetidamente; réplicas de deformidade são parametrizadas.
- Critério de reprovação: reposicionamento altera medida/enquadramento além da tolerância. Evidência: desenho e ensaio repetido.

### HW-04: Arranjo de iluminação por vista e difusão óptica

- Entrada: 2x LEDs RGB de 5 mm de alto brilho, lente difusora (PLA 3D branco translúcido, acrílico ou papel vegetal), fita retrorrefletiva 3M e sinais PWM de controle.
- Critério: acionamento direto dos LEDs RGB em potência máxima (luz branca) operados em modo estroboscópico via trigger do ESP32; obrigatoriedade do uso de lente difusora frontal para eliminação de hotspots rígidos em garrafas de PET/Vidro; alinhamento óptico do sensor E18-D80NK inclinado em 10°–15° mirando no anteparo retrorrefletivo oposto.
- Critério de reprovação: iluminação contínua gerando aquecimento e descarregamento de bateria, ou ausência de difusor provocando reflexos saturados.
- Evidência: fotos pareadas com e sem lente difusora, relatório de temperatura e logs de consumo das fonte de alimentação declarada no BOM (USB/serial; sem bateria no núcleo).

### HW-05: BOM e interfaces

- Critério: cada placa, câmera, sensor, atuador, alimentação e cabo tem modelo, interface e quantidade.
- Critério de reprovação: “câmera USB” ou “sensor” sem identificação reproduzível. Evidência: BOM versionada.

### HW-06: Segurança física e térmica

- Critério: alimentação, ventilação, cabos, partes móveis e parada segura são inspecionados antes da demo.
- Critério de reprovação: atuador acessível sem parada ou Pi superaquecendo sem alerta. Evidência: checklist e medição.

### ENV-01: Condições do ensaio

- Critério: registrar iluminação, velocidade, resolução, câmera, posição, temperatura e versão do modelo.
- Critério de reprovação: comparar resultados de setups diferentes sem qualificação. Evidência: manifest do ensaio.

## Machine learning e dataset

### ML-01: Taxonomia e rótulos

- Critério: classes, severidade e exemplos são definidos antes do treino e ligados à vista esperada.
- Critério de reprovação: rótulo ambíguo ou erro técnico classificado como defeito físico. Evidência: taxonomia e exemplos.

### ML-02: Splits sem vazamento

- Critério: treino, validação e teste não compartilham fotos do mesmo item/replicação.
- Critério de reprovação: hash ou grupo de item aparece em splits distintos. Evidência: manifest e script de verificação.

### ML-03: Proveniência de imagens

- Critério: cada imagem registra origem, licença/uso, classe, câmera, data e hash.
- Critério de reprovação: imagem sem origem ou dataset público tratado como fonte primária. Evidência: manifest.

### ML-04: Generalização honesta

- Critério: classificador de garrafa não sustenta claim de generalização; objetos novos só testam a camada geométrica, se aprovada.
- Critério de reprovação: objeto fora do treino aceito pelo classificador específico como prova geral. Evidência: protocolo separado.

### ML-05: Camadas condicionais

- Critério: CutPaste/NSA, descritores, cross-view, teacher-student e weak supervision têm PoC própria, métrica, latência e fallback.
- Critério de reprovação: camada entra no núcleo somente por existir no documento. Evidência: ficha de PoC.

### ML-06: Modelo no hardware alvo

- Critério: inferência INT8 e latência são medidas no Pi 5, com runtime, resolução e modelo registrados.
- Critério de reprovação: benchmark de Jetson/GPU usado como resultado do Pi. Evidência: benchmark no alvo.

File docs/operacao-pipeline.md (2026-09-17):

# Operação: gatilho, captura, inferência e registro

Este guia descreve o que está implementado na árvore atual. Ele descreve a ligação entre os serviços
presentes no repositório sem inventar integração.

## 1. As três rotas existentes

O sistema tem serviços conectados, mas cada fronteira usa contrato próprio. A ponte serial recebe o
trigger e comanda a câmera; o gateway HTTP conversa com rig e ponte; a ingestão e a inferência
persistem no SQLite. As três rotas abaixo explicam as entradas e contratos:

```text
A. Trigger -> ponte -> visão
   trigger-node (E18, GPIO27) -> esp32cam_site.py (ponte)
   -> CMD_TRIG -> ESP32-CAM (debounce 50 ms / cooldown 250 ms)
   -> uma foto -> frame UART com CRC

B. Inferência por diretório
   <capturas>/<item>/[lateral1.jpg,lateral2.jpg,topo.jpg]
   -> contrato do pacote -> YOLO -> decisão -> SQLite

C. Ingestão de série manifestada
   <serie>/manifest.json + fotos + mapa câmera->vista
   -> cópia de evidência -> artefato .npz legado -> decisão -> SQLite
```

A rota A inclui o nó de trigger e o receptor: `src-production/firmware/trigger-node/esp/main.py` lê o E18-D80NK
(GPIO27, active low), aplica debounce e abertura da janela; `esp32cam_site.py` é dona das portas
seriais, decodifica frames com `transport_bin.py`, recebe o trigger e envia `CMD_TRIG` à câmera. O
serviço de rig (`rig_service/app.py`) captura as três câmeras, grava a série com manifest e expõe as
rotas que `api.py` encaminha por `PNAAT_RIG` e `PNAAT_PONTE`. O código da cadeia está no repositório;
endereços, portas e diretório de séries são configuração da instalação.

## 2. Rota A: trigger e firmware

A rota tem dois nós de firmware, cada um no seu diretório. O código do trigger com o sensor está em
`src-production/firmware/trigger-node/`, e o nó de visão em `src-production/firmware/esp32cam-test/`.
A ponte serial (`esp32cam_site.py`) é quem religa o evento de um ao comando do outro.

### 2.1 Nó de trigger (E18-D80NK + ESP32, MicroPython)

Código: `src-production/firmware/trigger-node/esp/main.py` (firmware) e `presence.py` (máquina de estados pura,
testada). Pinos adotados no firmware: `PRESENCE_PIN = 27` (active-low, pull-up) e
`CAPTURE_OUT_PIN = 26`; a validação elétrica do sensor real continua pendente. O esquemático
normativo está em `docs/diagramas/interligacao-eletrica.mmd`; o ZIP Wokwi é histórico.

O nó lê o E18-D80NK a cada `DEBOUNCE_MS = 20 ms`, só arma após repouso contínuo de `ARM_MS = 500 ms`
(elimina a janela espúria do boot), abre a janela após `STABLE_READS = 5` leituras de presença,
fecha após `MISS_READS` de ausência e mantém guarda anti-duplicação de `GUARD_MS = 500 ms`. Cada
transição sai como `EV <evento> campo=valor`, também gravado em CSV no board; heartbeat do nível em
`PING_MS`. Gravação e monitor no ESP32:

```bash
cd src-production/firmware/trigger-node/host
.venv/bin/python esp_tool.py upload ../esp/main.py main.py
.venv/bin/python esp_tool.py run main.py --segundos 30
```

### 2.2 Nó de visão (ESP32-CAM, ESP-IDF)

Código: `src-production/firmware/esp32cam-test/main/main.c`. A câmera recebe um comando de captura (da ponte, via
`CMD_TRIG`, ou direto do sensor no `SENSOR_GPIO = GPIO_NUM_13`, fonte `TRIGGER_SOURCE_E18`), aplica
`DEBOUNCE_US = 50 ms` e `COOLDOWN_US = 250 ms`, acorda a câmera, captura uma imagem e publica um frame
com `event_id`, timestamp e CRC. Entre fotos, a câmera fica em standby. Onde existir a placa de
trigger dedicada, o E18 fica no nó MicroPython (GPIO27) e a ponte encaminha o evento em `CMD_TRIG`.

O transporte é UART, em texto ou binário. O formato binário usa SOF, cabeçalho, CRC16 e CRC32 do
payload. `esp32cam_site.py` (ponte) recebe o frame, atualiza o estado do enlace e disponibiliza as
operações do rig por HTTP. A suíte do firmware prova a publicação de uma foto por trigger, o descarte
de frame parcial e a compatibilidade de CRC. A ingestão de série é uma etapa distinta: recebe a série
já materializada pelo serviço de rig.

Para compilar e gravar o nó de visão:

```bash
cd src-production/firmware/esp32cam-test
idf.py set-target esp32
idf.py build
idf.py -p /dev/ttyUSB0 flash monitor
```

O uso de `/dev/ttyUSB0` é só exemplo. Na bancada, selecione a porta real por identificador estável.
A ligação elétrica do E18-D80NK com o nó de trigger está documentada em `docs/hardware.md` e no
esquemático Wokwi; consulte antes de conectar o sensor ao GPIO.

## 3. Rota B: inferência YOLO sobre uma captura materializada

Esta é a rota de operação do pacote detector. Ela exige que o serviço de captura já tenha gravado as
três imagens de um item no layout abaixo:

```text
<CAPTURA>/
  <ITEM>/
    lateral1.jpg
    lateral2.jpg
    topo.jpg
```

`CAPTURA` é a pasta pai de `<ITEM>`, não a pasta do item. A orquestração lê o `mtime` das fotos,
confere janela temporal e alinhamento declarado. Sem `--janela`, nenhuma vista é utilizável. Arquivo
duplicado para a mesma vista, ou bytes repetidos entre vistas, também excluem a vista da decisão.

O pacote precisa conter peso, contrato de pré-processamento, metadados, manifesto e `SHA256SUMS`.
Antes de carregar YOLO, `pacote_detector.py` confere o inventário e `preparo_detector.py` confere o
fingerprint, a orientação, a ROI, as classes, `imgsz` e os limiares. O recorte usado no runtime vem do
contrato, não de argumento livre.

```bash
make -C src-production smoke-detector   PACOTE=/caminho/pacote-detector   CAPTURA=/caminho/capturas   ITEM=ITM-001   DB=/caminho/hub.db   JANELA=0.4   ALINHAMENTO=declarado   EQUIPAMENTO=rig   LOCALIZACAO=bancada
```

Esse comando escreve no SQLite. Use um banco descartável ao aprender ou testar. O pacote lateral decide
apenas o domínio `tampa` nas vistas laterais; para `corpo`, o classificador retorna sem medida. O
detector de topo existe no acervo (`*-topo-detector-roi`) e atua como check dimensional. A conformidade
mantém o item como `inconclusivo` quando falta medida exigida; ela não transforma falta de evidência em
aprovação. Um defeito de tampa pode, contudo, reprovar o item.

## 4. Rota C: ingestão de série do rig

`ingerir_serie.py` recebe uma série já pronta com `manifest.json`. O manifest identifica as fotos e o
mapa `camera -> vista` associa cada câmera a `lateral1`, `lateral2` ou `topo`. O mapa é obrigatório e
pertence à instalação, porque trocar uma lateral altera a decisão.

```bash
.venv/bin/python src-production/ingerir_serie.py   --serie /caminho/serie   --lote L1   --db /caminho/hub.db   --roi 0.0 0.0 1.0 1.0   --mapa csi=topo,usb=lateral2,espcam=lateral1   --janela-ms 2000   --alinhamento declarado
```

A ingestão copia evidências, reserva `item_id`, executa a decisão e registra a transação. Se existir um
evento de gatilho já persistido, `--gatilho-id` cria o vínculo depois da ingestão. O vínculo é único:
um gatilho não pode apontar para dois itens.

Esta rota usa o artefato `.npz` legado indicado por `--modelo`; ela não aceita `--pacote-modelo` e não
carrega YOLO. Não a apresente como equivalente ao comando `smoke-detector`.

## 5. Registro de gatilho e API

Há dois meios de gravar um `evento_gatilho`: `fonte_gatilho.py`, que valida um CSV inteiro antes de
gravar, e `POST /api/gatilho`, que valida timestamp, estado e tipos. Ambos só persistem o evento. Eles
não acionam captura, ingestão ou inferência.

A API e o site podem ser usados com um banco local:

```bash
.venv/bin/python src-production/api.py --db hub.db --porta 8080 --host 127.0.0.1
```

Bind fora do loopback requer token. Endereços do serviço de câmera, ponte serial e adaptador de modelo
são configurados por ambiente; eles não fazem parte do clone nem devem ser publicados na documentação.

## 6. Decisão e banco

`orquestracao.executar()` prepara as vistas decisórias, chama o classificador por domínio e passa as
medidas para `decisao.py` e `conformidade.py`. A regra é fail-closed:

- sem evidência utilizável, o resultado é `inconclusivo`;
- `normal` não apaga um defeito mais confiante;
- qualquer defeito confirmado reprova;
- a vista de topo não aprova um item;
- `Registro.registrar()` é idempotente por `item_id` e recusa evidência divergente para o mesmo item.

O registro SQLite guarda item, inspeções por vista, gatilhos e evidências na mesma transação. Falha ao
gravar evidência causa rollback; o dashboard lê esse banco, não uma cópia de estado em memória.

## 7. Verificar o que foi instalado

A suíte do produto cobre esses serviços no nível de rota e lógica:

```bash
make -C src-production verificar
make -C src-production lint
make -C src-production test-trigger
make -C src-production trigger-simular
make -C src-production test-rig
```

O manual completo com pré-requisitos, firmware, serviços na ordem e ciclo de ponta a ponta está em
`docs/replicacao-ponta-a-ponta.md`.

### Sem hardware: banco local e API

```bash
make -C src-production verificar
make -C src-production lint
```

Sem câmera, sem peso e sem dado externo, a API ainda sobe contra um banco local. Em banco novo, o
`/api/health` cria o schema; o site serve os dados que estiverem no banco.

```bash
.venv/bin/python src-production/api.py --db hub.db --porta 8080 --host 127.0.0.1
```

Não existe alvo de demonstração nesta entrega. Os números de itens e estados só aparecem depois de uma
ingestão (rota C) ou de uma inferência por diretório (rota B) gravadas no mesmo banco.

## 8. Fonte de cada afirmação

| Assunto | Código ou documento |
|---|---|
| Firmware, trigger e frame serial | `src-production/firmware/esp32cam-test/` e `docs/hardware.md` |
| Captura por diretório e janela | `src-production/captura.py`, `src-production/orquestracao.py` |
| Série manifestada | `src-production/ingerir_serie.py`, `src-production/mapeamento_rig.py` |
| Pacote, contrato e YOLO | `src-production/pacote_detector.py`, `preparo_detector.py`, `classificador_yolo.py` |
| Decisão e persistência | `src-production/decisao.py`, `conformidade.py`, `registro.py` |
| Dataset e treino | `dataset/README.md`, `src-production/treino/README.md` |
| CAD e limites de fabricação | `cad-produto/README.md`, `docs/hardware.md` |

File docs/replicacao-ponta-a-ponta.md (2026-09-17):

# Replicação de ponta a ponta

Manual para levar o sistema do zero até a cadeia completa em um ambiente novo. Ele descreve os
componentes que existem neste repositório e a ordem em que são instalados e executados. Configuração
de instalação (endereços, portas, diretórios) é declarada por ambiente; não há valor pessoal no
arquivo.

## 1. Organização da cadeia

```text
sensor E18-D80NK
   -> trigger-node (ESP32 MicroPython, PRESENCE_PIN=27)
   -> ponte serial esp32cam_site.py  (dona da porta; CMD_TRIG)
   -> ESP32-CAM (uma foto por trigger, frame UART com CRC)
   -> rig_service (captura-3-cameras + série/manifest em PNAAT_SERIES_DIR)
   -> ingerir_serie.py (manifest + mapa câmera->vista)
   -> orquestracao/classificador (pacote YOLO) -> decisao/conformidade
   -> registro SQLite -> api.py -> site
```

Duas formas de executar o mesmo núcleo descrito acima:

- **Com hardware**: as rotas acima, com câmera, sensor e portas reais.
- **Sem hardware**: `make -C src-production verificar`, `test-trigger` e `test-rig` rodam a lógica
  com câmera falsa e dados isolados; `trigger-simular` reproduz os eventos do firmware sem placa.

## 2. Pré-requisitos

| Item | Uso |
|---|---|
| Linux (x86-64 ou ARM64) | Python, câmeras, ESP e serial |
| Python >= 3.11 e < 3.13 | produto, testes e ferramentas |
| ESP-IDF v5.x | compilar e gravar a ESP32-CAM |
| portas seriais identificáveis | ponte e trigger node por `by-id` |
| câmera CSI, webcam USB, ESP32-CAM | três vistas: topo, lateral1, lateral2 |
| E18-D80NK | sensor de presença do trigger |

Para a inferência YOLO e o treino, GPU com `torch`/`ultralytics` e o pacote detector em
`PNAAT_MODELOS`/`--pacote-modelo`. O pacote do entregável está publicado em
https://huggingface.co/Nerton/pnaat-modelos, com `SHA256SUMS` por pacote, então não é
preciso treinar para consumir o detector. Sem isso, a API, o registro e as rotas de
leitura ainda operam.

## 3. Clone e ambiente

```bash
git clone <url-do-repositorio> && cd tcc-pnaat
make install
```

O `make install` cria `.venv` na raiz e instala o pacote `src-production[dev,leitura,serial]`. As PoCs
foram removidas deste checkout e não são necessárias. Para treino e YOLO:

```bash
.venv/bin/python -m pip install -e "src-production[inferencia]"
```

## 4. Firmware

### 4.1 Nó de visão: ESP32-CAM

```bash
cd src-production/firmware/esp32cam-test
idf.py set-target esp32
idf.py build
idf.py -p /dev/ttyUSB-CAM flash monitor
```

O firmware faz uma foto por trigger (`CMD_TRIG`), standby entre fotos e frame UART com CRC. O
contrato binário e o receptor estão em `transport_bin.py`; a suíte cobre transporte, CRC, lacunas e
duplicatas (17 testes).

### 4.2 Nó de trigger: ESP32 + E18-D80NK

```bash
.venv/bin/python src-production/firmware/trigger-node/host/esp_tool.py \
  --porta /dev/serial/by-id/<ESP32-trigger> upload \
  src-production/firmware/trigger-node/esp/main.py main.py
.venv/bin/python src-production/firmware/trigger-node/host/esp_tool.py \
  --porta /dev/serial/by-id/<ESP32-trigger> run main.py --segundos 30
```

Pinos adotados e exercitados no firmware: `PRESENCE_PIN=27`, `CAPTURE_OUT_PIN=26`; os níveis do
sensor real ainda precisam de medição. O esquemático normativo está
em `docs/diagramas/interligacao-eletrica.mmd`; o ZIP Wokwi é apenas histórico e não fecha a ligação
ao GPIO27. A saída do sensor é NPN active-low; use divisor de nível se medir 5 V no sinal. A lógica
pura (`presence.py`) tem 5 testes.

## 5. Serviços (ordem de subida)

### 5.1 Ponte serial (rodada no nó de visão)

```bash
.venv/bin/python src-production/firmware/esp32cam-test/esp32cam_site.py \
  --porta 8094 --host 127.0.0.1 \
  --serial /dev/serial/by-id/<camera> --serial-trigger /dev/serial/by-id/<trigger>
```

A ponte é dona única das portas, lê o trigger, comanda a captura e publica status em `PNAAT_PONTE`
(default `http://127.0.0.1:8094`).

### 5.2 Serviço de rig (três câmeras, série e manifest)

```bash
export PNAAT_SERIES_DIR=/caminho/das/series/series-3-cameras   # obrigatório
export PNAAT_PONTE=http://127.0.0.1:8094                        # ponte acima
.venv/bin/python src-production/rig_service/app.py --porta 8090
```

Rotas principais do rig: `/estado`, `/dataset-series`, `/historico`,
`/teste-trigger-3-cameras`, `/configurar-delay`, `/capturar-3-cameras` e
`/series-3-cameras/<serie>/<arquivo>`. A captura grava a série com `manifest.json` e os JPEGs das
três câmeras em `PNAAT_SERIES_DIR`.

### 5.3 Gateway da API e site

```bash
export PNAAT_RIG=http://127.0.0.1:8090
export PNAAT_PONTE=http://127.0.0.1:8094
.venv/bin/python src-production/api.py --db hub.db --porta 8080 --host 127.0.0.1
```

O gateway expõe as rotas de consulta e as operações de rig/ponte; bind fora do loopback exige token
Bearer. O site é servido na mesma origem.

## 6. Ciclo de ponta a ponta

1. O item passa pelo E18-D80NK; o trigger-node abre a janela e publica `CAPTURE_WINDOW_OPEN`.
2. A ponte recebe o trigger, envia `CMD_TRIG` à ESP32-CAM e guarda o frame.
3. O operador (ou o autômato da instalação) pede `POST /api/rig/captura`; o rig grava a série
   `series-3-cameras/<serie>/` com `manifest.json`.
4. A série é importada para o registro:

```bash
.venv/bin/python src-production/ingerir_serie.py \
  --serie "$PNAAT_SERIES_DIR/<serie>" --lote L1 --db hub.db \
  --roi 0.0 0.0 1.0 1.0 \
  --mapa csi=topo,usb=lateral2,espcam=lateral1 \
  --janela-ms 2000 --alinhamento declarado
```

5. `orquestracao.executar()` roda a única cadeia de decisão: pré-processamento, classificador por
   domínio, conformidade e registro idempotente por `item_id`.
6. O site/API consultam o SQLite; o operador pode registrar correção append-only.

O mapa `camera -> vista` é dado da instalação e não tem default; trocar a ordem das laterais muda a
decisão, por isso é sempre declarado.

## 7. Verificação

| O quê | Comando | Esperado |
|---|---|---|
| Produto e firmware | `make -C src-production verificar` | sem falhas; termina com `produto e firmware verificados` |
| Lint | `make -C src-production lint` | `All checks passed!` |
| Trigger (lógica pura) | `make -C src-production test-trigger` | 5 passed |
| Trigger (simulador) | `make -C src-production trigger-simular` | janelas esperadas por caso |
| Rig (câmera falsa) | `make -C src-production test-rig` | `teste das rotas: 24 ok, 0 falha` |
| Rig (bordas) | `python src-production/rig_service/testes_edge.py` | `49 ok, 0 falha` |
| API | `curl http://127.0.0.1:8080/api/health` | JSON 200 |
| Rig | `curl http://127.0.0.1:8090/estado` | JSON com estado da captura |
| Ponte | `curl http://127.0.0.1:8094/status` | JSON com serial/frames |

## 8. Dados externos que não viajam no repositório

| Artefato | Para quê | Como apontar |
|---|---|---|
| `PNAAT_SERIES_DIR` | séries do rig e manifest | obrigatório no serviço de rig |
| `PNAAT_MODELOS` | pesos, runs e datasets de treino | usado pelos alvos `treino-*` e `pacote` |
| pacote detector | inferência YOLO | `make smoke-detector PACOTE=...` ou `orquestracao.py --pacote-modelo` |
| export do Label Studio | criação do dataset | consumido por `monta_v1_detector.py` |

Esses valores são dados do ambiente de instalação. O repositório guarda o código, o contrato, o
índice (`models/INDEX.csv`) e as amostras de método; peso e acervo bruto ficam fora por política, e
os pacotes de modelo do entregável estão publicados em https://huggingface.co/Nerton/pnaat-modelos.

## 9. Limites de ambiente

- Sem o pacote YOLO, a API, o registro e o site continuam funcionando; itens sem medida ficam
  `inconclusivo` na conformidade.
- Sem as câmeras e o sensor, `test-rig` e `trigger-simular` provam as rotas e a lógica sem hardware;
  validação física (níveis elétricos, debounce, cooldown) é trabalho de bancada, não ausência de
  código.

## 10. Docker

A composição em `docker/` empacota os três serviços em uma imagem única (base `python:3.11-slim`,
pacote `src-production[dev,leitura,serial,inferencia]` + repositório inteiro). Build a partir da
raiz do repositório (contexto `..`); o `.dockerignore` da raiz exclui `.venv`, `dataset`, `models`
e `.git` da imagem.

```bash
docker compose -f docker/docker-compose.yml build   # imagem tcc-pnaat:local (torch/ultralytics: build pesado)
export PNAAT_API_TOKEN='troque-este-token'
docker compose -f docker/docker-compose.yml up -d api       # sem hardware: só o núcleo
# com hardware (câmeras e portas seriais): docker compose --profile hardware -f docker/docker-compose.yml up -d
curl -H "Authorization: Bearer $PNAAT_API_TOKEN" http://127.0.0.1:8080/api/health
docker compose -f docker/docker-compose.yml ps
docker compose -f docker/docker-compose.yml logs -f api
```

Serviços:

| Serviço | Comando no container | Porta | Exigência |
|---|---|---|---|
| `api` | `python src-production/api.py --db /data/hub.db --porta 8080 --host 0.0.0.0` | 8080 | nenhuma: sobe sem hardware (núcleo) |
| `rig` | `python src-production/rig_service/app.py --porta 8090` | 8090 | `PNAAT_SERIES_DIR`; câmeras opcionais |
| `ponte` | `python src-production/firmware/esp32cam-test/esp32cam_site.py --porta 8094 --serial /dev/ttyUSB0 --serial-trigger /dev/ttyUSB1` | 8094 | devices `/dev/ttyUSB*` reais |

Variáveis de instalação (compose):

| Variável | Serviço | Padrão | Uso |
|---|---|---|---|
| `PNAAT_SERIES_DIR_HOST` | rig | `./series` (cria `docker/series/`) | bind do diretório de séries do host em `/series` |
| `PONTE_SERIAL_CAM` | ponte | `/dev/ttyUSB0` | device da ESP32-CAM |
| `PONTE_SERIAL_TRIGGER` | ponte | `/dev/ttyUSB1` | device do trigger-node |
| `PNAAT_API_TOKEN` | api | obrigatório, sem padrão | Bearer token; a API recusa bind fora do loopback sem token (api.py:1373) |

O `hub.db` vive no volume nomeado `hub-db` (montado em `/data`, pré-criado com o dono do usuário
não-root `app`, uid 1000, igual ao uid do nerton no host). Healthchecks por `urllib` (sem curl na
imagem): `api` → `/api/health`, `rig` → `/estado`, `ponte` → `/status`.

Limites: `ponte` e `rig` exigem devices reais (seriais das ESPs e câmeras). Sem eles os serviços
sobem, mas ficam degradados (a ponte serve `/status` com serial fechada). Sem hardware, só o `api`
é útil; para validar a lógica inteira sem placa use os alvos da seção 7.

## 11. Flash das duas ESPs

Comandos prontos (rodando da raiz do repositório):

```bash
# ESP32-CAM (nó de visão): exporte o ESP-IDF antes (source $IDF_PATH/export.sh)
make -C src-production/firmware flash-cam PORTA_CAM=/dev/serial/by-id/<ESP32-CAM>
#   equivalente: cd src-production/firmware/esp32cam-test &&
#     idf.py set-target esp32 && idf.py build && idf.py -p "$PORTA_CAM" flash monitor

# ESP32 (nó de trigger, MicroPython): usa o .venv da raiz e o esp_tool.py
make -C src-production/firmware flash-trigger PORTA_TRIGGER=/dev/serial/by-id/<ESP32-trigger>
#   equivalente: cd src-production/firmware &&
#     ../../.venv/bin/python trigger-node/host/esp_tool.py --porta "$PORTA_TRIGGER" \
#     upload trigger-node/esp/main.py main.py
```

Prefira `/dev/serial/by-id/...` (estável entre reboots) ao `/dev/ttyUSBn`. Exemplos:
`/dev/serial/by-id/usb-Silicon_Labs_CP210x_USB_to_UART_Bridge_<id>` na ESP32-CAM e
`/dev/serial/by-id/usb-1a86_USB_Serial_<id>` no ESP32 do trigger. Antes de gravar, identifique
cada placa (`ls -l /dev/serial/by-id/`); trocar as duas portas grava o firmware no lugar errado.

Confirmação no fio após o flash: a ESP32-CAM imprime `BOOT_TEST firmware=esp32cam_test
sensor_gpio=13 active=LOW`; o trigger imprime `EV READY pin=27 out=26` seguido de `EV PING`
a cada 2 s.

Pinos adotados no código `src-production/firmware/trigger-node/esp/main.py`:
`PRESENCE_PIN = 27` (linha 19, sinal do E18-D80NK, entrada com pull-up, active-low) e
`CAPTURE_OUT_PIN = 26` (linha 24, saída "capturando").

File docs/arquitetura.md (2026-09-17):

# Arquitetura

Este documento tem duas partes. A primeira é o desenho aprovado, com as expansões, incluindo
atuação, MQTT com hub e múltiplos nós. A segunda, no fim, descreve o que o código roda hoje, com o
que cada teste protege. Nada da primeira parte deve ser lido como implementado sem essa conferência.
O manual de replicação é o `README.md` da raiz.

## Arquitetura proposta

## Diagrama de blocos

```mermaid
flowchart LR
    %% Elementos físicos
    item[Item no trilho] --> encoder[Encoder KY-040\nvelocidade e contagem]
    item --> trigger[Trigger E18-D80NK\npresença do item]

    %% Nó de controle: ESP32
    subgraph esp32[Microcontrolador: ESP32]
        debounce[Debounce e\ntratamento do sinal]
        janela[Cálculo da janela\nde captura]
        trigger --> debounce
        encoder --> janela
        debounce --> janela
    end

    %% Nó de visão: Raspberry Pi 5
    subgraph rpi[Nó de visão: Raspberry Pi 5]
        captura[Janela de captura\nmesmo item_id]

        topo[Câmera topo\nCSI]
        lateral1[Câmera lateral 1\nCSI]
        lateral2[Câmera lateral 2\nUSB UVC]

        cls_topo[Classificador topo\ncheck dimensional]
        cls_lat1[Classificador lateral 1\ntampa + corpo]
        cls_lat2[Classificador lateral 2\ntampa + corpo]

        dominio_tampa[Domínio da tampa\nlaterais decidem]
        dominio_corpo[Domínio do corpo\nlaterais decidem]
        check_dim[Check dimensional\ntopo independente]

        fusao[Fusão por domínio\nstatus · confiança · discordância]

        captura --> topo
        captura --> lateral1
        captura --> lateral2

        topo --> cls_topo
        lateral1 --> cls_lat1
        lateral2 --> cls_lat2

        cls_lat1 --> dominio_tampa
        cls_lat2 --> dominio_tampa
        cls_lat1 --> dominio_corpo
        cls_lat2 --> dominio_corpo
        cls_topo --> check_dim

        dominio_tampa --> fusao
        dominio_corpo --> fusao
        check_dim --> fusao
    end

    janela -->|sinal de trigger + timestamp| captura

    %% Decisão e registro
    fusao --> decisao{Status do item}
    decisao -->|aprovado| registro[Registro local]
    decisao -->|defeito| atuador[Atuador\nseparação para análise]
    decisao -->|inconclusivo| registro

    atuador --> confirmacao[Confirmação]
    confirmacao -->|falha| qualidade[Evento de qualidade]
    atuador --> registro

    %% Telemetria e persistência
    sensores[Sensores paralelos\ntelemetria do nó] --> mqtt[MQTT · expansão]
    registro --> mqtt
    atuador --> mqtt

    mqtt --> hub[Hub local]
    hub --> db[(SQLite)]
    db --> dashboard[Dashboard]
    db --> relatorio[Relatório de lote]

    %% Estilos
    classDef physical fill:#fff3e0,stroke:#e65100,color:#111
    classDef vision fill:#e3f2fd,stroke:#1565c0,color:#111
    classDef data fill:#e8f5e9,stroke:#2e7d32,color:#111

    class item,encoder,trigger,atuador,confirmacao,sensores physical
    class topo,lateral1,lateral2,cls_topo,cls_lat1,cls_lat2,dominio_tampa,dominio_corpo,check_dim,fusao,decisao,captura vision
    class mqtt,hub,db,dashboard,relatorio,registro,qualidade data
```

## Fluxo do núcleo (resumo)

```text
evento de presença → captura multi-view (2 laterais + topo)
→ classificação por domínio (tampa nas laterais, corpo nas laterais, check dimensional no topo)
→ fusão por domínio → evento rastreável → registro local → dashboard e alertas
```

A arquitetura é proposta. Ela não comprova compatibilidade de hardware, sincronização, desempenho ou operação industrial.

## Componentes e funções

| Componente | Função prevista | Limite ou expansão |
|---|---|---|
| Sensor de presença + microcontrolador (ESP32) | Marca o evento de observação e inicia a janela de captura. | Sensor alternativo é avaliado na PoC-01 (D-20). |
| Multi-view (2 laterais + topo) | Captura mais de uma vista do item com identificador e timestamp. | Quantidade e posição de vistas são definidas por PoC (D-03). |
| Classificação por domínio | As duas vistas laterais decidem tampa e corpo; a vista de topo é um check dimensional independente (D-23). | Exige dataset e métricas por classe. |
| Fusão por domínio | Combina vistas dentro de cada domínio e preserva discordâncias. Defeito em qualquer domínio reprova o item (D-04). | Não substitui análise humana para casos ambíguos. |
| Nó de observação | Associa captura, localização, timestamp e resultado em evento rastreável. | Hub local e múltiplos nós são expansão. |
| Registro local | Persiste eventos e evita duplicidade por reenvio. | Contrato de persistência é validado na PoC-05. |
| Dashboard e alertas | Apresenta defeito, momento, localização, esteira, nó e evidência. | Não aciona a esteira nem atuação física. |

## Contrato mínimo do evento

Cada evento deve conter:

- `item_id` ou identificador de captura;
- timestamp com fuso;
- origem e localização;
- esteira, quando aplicável;
- vistas disponíveis;
- classe, confiança e qualidade do registro;
- referência ou hash da evidência;
- versão do contrato.

## Expansões controladas

MQTT, hub local, múltiplos nós, integração industrial, atuação física e confirmações mecânicas são extensões. Nenhuma delas deve ser apresentada como implementada ou necessária para validar o núcleo do projeto.

## Arquitetura implementada

O estado abaixo foi conferido contra `src-production/`. A arquitetura proposta no início deste arquivo
continua proposta; ela inclui a topologia física e os domínios sem modelo no pacote lateral
(CORPO). O detector de topo existe no acervo e atua como check dimensional.

```text
trigger-node (E18, GPIO27) -> ponte serial (esp32cam_site.py) -> CMD_TRIG -> ESP32-CAM
                                                                        |
                                              captura materializada (rig_service -> série/manifest)
capturas por diretório -> orquestracao.py -> pacote YOLO -> decisão -> registro SQLite

serie/manifest.json -> ingerir_serie.py -> artefato .npz legado -> decisão -> registro SQLite

CSV ou POST /api/gatilho -> evento_gatilho no SQLite
```

O receptor UART está em `firmware/esp32cam-test/esp32cam_site.py`: é dono da serial, decodifica frames
com `transport_bin.py`, recebe o trigger e envia o comando de captura. O serviço de rig
(`rig_service/app.py`) grava a série com manifest; `ingerir_serie.py` importa a série para o registro
e `orquestracao.executar()` roda a única cadeia de decisão. O desenho firmware -> receptor ->
`ItemCapturado` -> decisão -> registro é o comportamento atual; endereços, portas e diretórios são
configuração da instalação.

| Camada | Implementado | Limite observável |
|---|---|---|
| Trigger, ponte e foto | nó MicroPython (E18, GPIO27) + `esp32cam_site.py` (ponte) + ESP32-CAM (CMD_TRIG, debounce 50 ms/cooldown 250 ms, frame UART e CRC) | portas, endereço e implantação são dados da instalação |
| Evento de gatilho | CSV e API gravam `evento_gatilho` | gravar gatilho não dispara inferência |
| Captura materializada | `captura.py` valida layout, janela, alinhamento e duplicidade | depende de arquivos já gravados |
| Pacote YOLO | `pacote_detector.py`, `preparo_detector.py`, `classificador_yolo.py` | detector lateral decide tampa nas laterais; detector de topo existe no acervo (`*-topo-detector-roi`, `models/INDEX.csv`) e é usado como check dimensional — topo nunca decide aprovação (D-23/D-30) |
| Ingestão de série | `ingerir_serie.py` lê manifest, copia evidência e vincula gatilho | usa `.npz` legado, não pacote YOLO |
| Decisão e banco | `decisao.py`, `conformidade.py`, `registro.py` | ausência de medida necessária resulta em inconclusivo |
| API e site | `api.py`, `painel.py`, `consultas_site.py`, `site/` | site exibe capturas, fotos e séries do registro (`/api/evidencia`, `/api/series`, `/api/rig/series`); a captura em si vem do serviço de rig |

O comando `make -C src-production verificar` cobre produto e firmware. Para os comandos e layouts de
arquivo de cada rota, use `docs/operacao-pipeline.md`.

## Fonte de cada rota

`docs/operacao-pipeline.md` é o guia executável; os módulos citados acima são a fonte de comportamento.

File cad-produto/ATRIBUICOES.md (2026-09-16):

# Atribuições de modelos e referências de terceiros

Modelos e projetos baixados da internet e usados ou consultados neste trabalho.
A licença de cada um foi lida do arquivo que veio no próprio download, não de
busca na web.

## Modelos que entraram no produto

### Raspberry Pi 5 Din Rail

```
Autor ....... Diyalec
Fonte ....... Thingiverse, thing:6335141
Licença ..... Creative Commons Attribution-ShareAlike
Evidência ... LICENSE.txt do arquivo baixado
Uso ......... 02-impressao/case-pi-din/pi5-din-topside.stl
              e pi5-din-bottom-side.stl
```

O mesmo modelo está publicado no Printables 660057, listado lá com o autor alec, e
essa página declara que é remix de "Raspberry Pi DIN Rail Case", de mdkendall. O
desenho do autor em PDF que acompanha a pasta veio dessa página. Os nomes de autor
diferem entre as duas publicações.

### DIN Rail Bracket for M6 Bolts

```
Autor ....... ADSRMedia
Fonte ....... Printables, model 573570
Licença ..... Creative Commons Attribution-NonCommercial-ShareAlike 4.0
Evidência ... PDF da página do modelo, dentro do arquivo baixado
Uso ......... 02-impressao/base-trilho/, que expande o bracket já impresso
```

### Raspberry Pi 4B case with RPi camera 2 arm

```
Autor ....... Dominik Chuchlík
Fonte ....... Printables, model 301598
Licença ..... Creative Commons Attribution 4.0
Evidência ... PDF da página do modelo, dentro do arquivo baixado
Uso ......... 02-impressao/camera-lateral/
              housing, tampa, swivel e braço do suporte lateral
```

## Modelos oficiais da Raspberry Pi

```
Autor ....... Raspberry Pi Ltd
Licença ..... MIT, Copyright (c) 2026 Raspberry Pi Ltd
Evidência ... LICENSE.txt do pacote baixado
```

O pacote traz o modelo do Pi 5, os da Camera Module 3 nas versões padrão e wide, e
três desenhos mecânicos, entre eles o do cabo flexível de 200 mm. O aviso que
acompanha o modelo diz que ele serve só como orientação, sem garantia de exatidão,
e que quem for usá-lo para ajuste deve medir o produto físico.

### DIN-rail angle adapter

```
Autor ....... Shroamer
Fonte ....... Printables, model 1757341
Licença ..... Creative Commons Attribution-NonCommercial-ShareAlike 4.0
Evidência ... PDF da página do modelo, dentro do arquivo baixado
Uso ......... referência de adaptador de ângulo, não entrou no produto
```

### Breadboard din rail mount

```
Autor ....... Fellesverkstedet
Fonte ....... Thingiverse, thing:2705849
Licença ..... Creative Commons Attribution
Evidência ... LICENSE.txt do arquivo baixado
Uso ......... referência de fixação em trilho DIN, não entrou no produto
```

### Raspberry Pi Cam Holder for 30mm Alu Profile

```
Autor ....... DOMin8or
Fonte ....... Thingiverse, thing:5355988
Licença ..... Creative Commons Attribution
Evidência ... LICENSE.txt do arquivo baixado
Uso ......... referência de suporte de câmera, não entrou no produto
```

## Referências de software

### qwen-mm-plugins

```
Projeto ..... qwen-mm-plugins
Licença ..... Apache License 2.0
Evidência ... LICENSE na raiz do projeto baixado
Uso ......... plugin de FreeCAD usado durante o trabalho
```

## Modelos sem licença verificada

Estes foram baixados e não trazem licença dentro do pacote. A licença não foi
confirmada, e eles não devem ser redistribuídos sem essa confirmação.

```
Ender 5 Raspberry Pi camera case          pacote com 4 arquivos .stl
Case with Kodak thread for ESP32CAM CH340 pacote com 2 arquivos .stl
G-Clamp Tripod                            pacote sem licença
```

## Como as referências estão organizadas

`03-referencias/vendor/` é um link simbólico para uma área de referências que
fica fora deste diretório. Por isso ele não é copiado junto quando o projeto é
publicado, e o link deixa de funcionar em qualquer cópia.

O que está atrás do link, hoje:

```
raspberry-pi/               12 arquivos    modelos oficiais e desenhos mecânicos
din-rail-case/              13 arquivos    case do Pi 5 para trilho DIN
din-rail-parts/             18 arquivos    bracket M6, adaptador de ângulo, brutos
din-rail-standoff-2020/      4 arquivos    standoff para perfil 2020
g-clamp-tripod/              4 arquivos    referência de clamp
pi5-case-refs/             267 arquivos    projetos de referência de case para Pi 5
ender5-rpi-camera-case/      6 arquivos    case de câmera para Ender 5
qwen-mm-plugins/          1004 arquivos    plugin de FreeCAD
```

Dentro de `pi5-case-refs/` há quatro projetos distintos. O único com licença
explícita é `pcb-enclosure-generator`, MIT de Haden Cain. O diretório `pipiece`
tem um arquivo `LICENSE.sha256` cujo conteúdo é a palavra `no-LICENSE-file`, ou
seja, o próprio projeto declara não ter licença.

## Modelos próprios

O pórtico, os montantes, a travessa, as junções e a case da ESP32-CAM são geração
própria do projeto e não têm atribuição de terceiro.

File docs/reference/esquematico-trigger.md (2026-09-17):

# Esquemático do trigger (ESP32-S3 + sensor)

O projeto Wokwi original está na raiz em **`ESP32S3-Trigger.zip`**, contribuição de Paulo Victor
(commit `9fefd73`). Ele é uma referência histórica de protoboard, não um layout fabricável nem a
fonte normativa da ligação: usa um PIR genérico e seu `diagram.json` não materializa a ligação ao
GPIO27 adotado pelo firmware. O esquemático de interligação atualizado é
`docs/diagramas/interligacao-eletrica.mmd`; a pinagem normativa e o procedimento de medição estão em
`docs/hardware.md`, seção 2.

## O que o zip contém

| Arquivo | Papel |
|---|---|
| `wokwi-project.txt` | metadados do projeto Wokwi (id `475343904586369025`) |
| `sketch.ino` | esqueleto Arduino do ESP32-S3 (exemplo de inicialização) |
| `diagram.json` | o circuito: ESP32-S3 DevKitC-1, protoboard, divisor e sensor |

Reproduzir online: https://wokwi.com/projects/475343904586369025 (ou importar o zip em
`https://wokwi.com/projects/new/esp32-s3`).

## Ligações do diagrama

| Elemento | Ligação |
|---|---|
| ESP32-S3 DevKitC-1 | alimentação 3V3 e GND à protoboard |
| Sensor genérico (PIR simula o trigger) | VCC em 5V, GND comum, saída `OUT` no divisor |
| Resistor R1 de 2,2 kΩ | entre a saída do sensor e o GPIO (redução de nível) |
| Resistor R2 de 3,3 kΩ | do GPIO para GND (pull de referência) |
| GPIO | o arquivo histórico não fecha a ligação ao GPIO de produção; **GPIO27** é o pino do firmware |
| Serial | TX/RX no monitor serial, 115200 |

No produto, o sensor real é o E18-D80NK (NPN active-low, 5 V). R1/R2 só deve ser usado se a medição
do sinal livre indicar tensão acima de 3,3 V; para saída open-collector pura, usa-se GPIO27
diretamente com pull-up para 3,3 V.

## Relação com o firmware

O firmware MicroPython do nó de trigger (`src-production/firmware/trigger-node/esp/main.py`)
implementa a leitura do E18-D80NK com `PRESENCE_PIN = 27` e `CAPTURE_OUT_PIN = 26`, debounce de
20 ms, arming de 500 ms e guarda anti-duplicação de 500 ms. O esquemático documenta a montagem
física que esse firmware espera; a medição elétrica final (níveis reais de saída, divisor) é
validação de bancada pendente.

## Status

- Esquemático de referência: simula o trigger com sensor genérico (não é o E18 real no circuito).
- O firmware correspondente está versionado e testado (5 testes da lógica pura).
- Validação elétrica com o sensor físico real: pendência de bancada (ver `docs/hardware.md`).

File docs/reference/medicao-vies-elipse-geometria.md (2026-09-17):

# Medição: viés do ajuste de elipse e o que limita a metrologia da tampa

Data: 2026-09-11. Harness: `workspace/scripts/medir_vies_elipse.py` (determinístico, seed 1234,
200 trials por célula). Teste de regressão: `workspace/tests/test_vies_elipse.py`.

Motivo: o paper de Halir & Flusser (1998),
avisa que o ajuste por distância **algébrica** tem viés sistemático que encolhe a elipse. Como o
RF-15/RNF-14 mira 0,5 mm, era preciso saber se esse viés cabe no orçamento.

Escala assumida (estimativa até haver calibração Charuco): tampa nominal **28 mm** (PCO 1881) sobre
**45,8 px** medidos nas nossas frames → **0,611 mm/px**. Logo **0,5 mm ≈ 0,82 px**.

## Resultado (semi-eixos verdadeiros a=22,9 px, b=21,0 px, ângulo=30°)

| Arco visível | ruído σ | viés a (px) | viés a (mm) | viés b (px) | erro de ângulo (°) |
|---|---|---|---|---|---|
| 360° | 0,0 | −0,0000 | 0,0000 | 0,0000 | 0,000 |
| 360° | 0,25 | +0,0028 | 0,0017 | 0,0039 | 0,321 |
| 360° | 0,5 | +0,0100 | 0,0061 | 0,0147 | 0,643 |
| 360° | 1,0 | +0,0377 | 0,0230 | 0,0571 | 1,297 |
| 360° | 2,0 | +0,1489 | 0,0910 | 0,2211 | 2,679 |
| 270° | 0,0 | −0,0000 | 0,0000 | 0,0000 | 0,000 |
| 270° | 0,5 | −0,0123 | −0,0075 | −0,0045 | **1,332** |
| 270° | 1,0 | −0,0334 | −0,0204 | −0,0220 | **4,135** |
| 270° | 2,0 | −0,0040 | −0,0024 | −0,1023 | **12,825** |

RANSAC não muda o quadro (σ=1, 270°: 3,61°; σ=2: 13,68°): ele rejeita outliers, não recupera arco
ausente.

## Leitura

1. **O viés algébrico do Halir não é o gargalo.** Com contorno completo e ruído plausível de borda
   (σ=1 px), o encolhimento é **0,038 px = 0,023 mm**; em σ=2 px, 0,091 mm. Ambos **dentro** do
   orçamento de 0,5 mm. Refino geométrico não é obrigatório para o semi-eixo: fica como margem.
2. **O gargalo é oclusão do contorno.** Faltando 25% do arco (270° visível, ex.: anel de suporte
   escondendo parte da tampa), o **erro de ângulo** sobe de 1,30° → **4,13°** (σ=1) e a 12,8° (σ=2).
   A precisão angular não depende do ajuste, depende de **ver a maior parte do contorno**.
3. **Tradução para mm (o que importa para `tampa_mal_rosqueada`)**: com raio da tampa R≈14 mm,
   `Δh ≈ R·sin(θ)`. Erro de 1,3° ≈ **0,32 mm** (dentro dos 0,5 mm); erro de 4,1° ≈ **1,00 mm**
   (fora). Ou seja, **a classe tampa_mal_rosqueada só é decidível em mm se o contorno estiver
   suficientemente visível**.
4. **Resolução é limite físico separado**: 1 px = 0,611 mm hoje; como 0,5 mm ≈ 0,82 px, a meta exige
   **localização subpixel de borda** (~0,1-0,2 px) ou aproximar/alongar a óptica da tampa. O contorno
   atual vem de `cv2.findContours` (pixel inteiro) → σ≈1 px é justamente o cenário do caso 360°/σ=1.

## Consequências práticas (acionáveis)

- **Checklist de captura da tampa**: garantir ≥300° de contorno visível da tampa (mover o anel de
  suporte fora do campo ou usar a vista em que a tampa não é ocluída): vale mais que qualquer
  melhoria de algoritmo.
- **Subpixel obrigatório** para a meta de 0,5 mm: próximos passos são (a) medir o σ real de
  localização de borda nas nossas frames e (b) avaliar extração subpixel (ajuste de borda por
  gradiente/parabólico) antes de prometer número em mm.
- **Métrica de qualidade nova** a instrumentar: **fração de arco visível da tampa**. Sem ela, um
  resultado de tilt não é interpretável: é a versão "ângulo" do que já fazemos com CNR/especular.
- **Não** gastar esforço em refino geométrico da elipse agora (o viés está sob controle); o esforço
  vai para visibilidade do contorno + subpixel.

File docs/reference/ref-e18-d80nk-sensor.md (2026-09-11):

# Ref: sensor E18-D80NK (IR difuso, NPN NO): nosso exemplar + datasheet

Ingest em 2026-09-11. Fontes: label do **nosso exemplar** (informado por Nerton) e datasheets de
terceiros. Status por claim: `P` datasheet verificado · `U` informado pelo usuário (nosso hardware) ·
`F` divergente/contraditório · `X` não confirmado.

## Nosso exemplar (o que está fisicamente em mãos)

| Campo | Valor | Status |
|---|---|---|
| Label impresso | **5VDC: 100mA** | `U` |
| Fios | **3**: **bege (= +5V)**, preto (sinal), azul (GND) | `U` (confirmado) |
| Tipo | sensor IR difuso de proximidade, corpo cilíndrico roscado | `U`/`P` |

✅ **Mapeamento do nosso exemplar CONFIRMADO** (informado por Nerton, 2026-09-11):
**bege = +5V** (equivale ao marrom do padrão), **preto = sinal**, **azul = GND**.
O datasheet de referência usa marrom no lugar do bege: em outro lote, **reconfirme por função**
(a cor não é convenção garantida entre fabricantes).

## Dados de datasheet (terceiros: divergências registradas)

| Especificação | Valores encontrados | Status |
|---|---|---|
| Tensão de alimentação | **5 VDC** (Handson, e-Gizmo); variantes de mercado anunciam 5-24 V e 10-30 V | `P` + `F` (variantes) |
| Consumo | **25-100 mA** (Handson); **100 mA** (e-Gizmo, como *load current*); `<25-30 mA` em anúncios de outra variante | `P` + `F` |
| Faixa de detecção | **3 cm a 80 cm**, ajustável por potenciômetro multi-volta | `P` |
| Tipo de saída | **NPN normalmente aberto (open collector)**, 3 fios | `P` |
| Lógica | **1 = sem detecção · 0 = objeto detectado** (ativo em nível BAIXO) | `P` |
| Objeto detectável | "transparente ou opaco" (declaração do fabricante) | `P` |
| Tempo de resposta | **< 2 ms** | `P` |
| Ângulo de detecção | ≤ 15° | `P` |
| Dimensões | Ø 17-18 mm × 45 mm (cabo 45 cm a 1 m) | `P` |
| Temperatura | −25 °C a 55 °C (um datasheet: 70 °C) | `P` + `F` |
| Luz ambiente | incandescente 3000 lx / solar 10000 lx máx. | `P` |

Fontes: Handson Technology *User Guide* (SKU SSR1069); e-Gizmo/Mechanotrix *Technical Manual* Rev 1.0
(modelo E18-D80NK-N); anúncios de variantes (ielectrony, besomi). As divergências são reais entre
lotes/vendedores: por isso o número que vale para o projeto é **o do nosso exemplar + a medição**.

## Consequências para o projeto (acionáveis)

1. **Orçamento de energia**: reservar **≥ 100 mA em 5 V** para o sensor. Alimentar do **rail 5 V**
   (USB da dev board) e **nunca** do pino 3,3 V. Se usar fonte de bancada, limitar corrente
   (~150 mA) no primeiro teste: protege contra inversão de polaridade.
2. **Nível lógico**: a saída é **open collector**. Dois casos possíveis, decididos por medição:
   - módulo **sem** pull-up interno → ligar direto ao GPIO com `PULL_UP` do ESP32 (3,3 V): o nível
     nunca excede 3,3 V ✔;
   - módulo **com** pull-up interno para 5 V → usar divisor (ex.: 2k2 série + 3k3 para GND) ou
     level shifter; **não** ligar direto.
3. **Lógica ativa em baixo confirmada pelo datasheet** (`0 = objeto detectado`): nossa conversão
   `present = (level == 0)` está correta.
4. **PET transparente é o caso difícil** apesar da folha de dados dizer "transparente ou opaco": a
   detecção difusa depende de superfície que devolva IR ao receptor. Testar **garrafa vazia e cheia**
   e registrar: é a evidência que a PoC exige.
5. **Pitfalls**: superfície muito reflexiva ou muito escura altera a distância efetiva; luz ambiente
   acima dos limites do datasheet aumenta falso disparo; o potenciômetro multi-volta exige ajuste
   fino e **registro** do ponto usado.

## Procedimento de identificação dos fios (antes de energizar)

1. **Mapeamento**: `bege = +5V`, `preto = sinal`, `azul = GND` (confirmado para o nosso exemplar).
2. **Fonte com limite de corrente** em 5 V / 150 mA. Ligue bege no +5 V e azul no GND.
   - LED do módulo acende e o consumo fica na faixa de dezenas de mA → polaridade correta.
   - Consumo no limite ou nada acende → **desligue imediatamente** e reconfira o mapeamento.
3. **Confirme o sinal**: multímetro VDC entre **preto** e GND: ~5 V livre, **~0 V com objeto a
   10-30 cm**.
4. Só depois ligue o preto no GPIO (com `PULL_UP`, ou com divisor se a medição do passo 3 mostrar
   que o pino sobe a 5 V).

## Critério de aceitação do componente

- **10 aproximações → 10 detecções** na distância de trabalho escolhida (começar em ~15 cm);
- mesmo resultado com **garrafa cheia** e **vazia** (ou registro explícito da diferença);
- consumo medido dentro do orçamento (≤ ~100 mA);
- distância e ponto do potenciômetro **registrados** (foto/marca no corpo).

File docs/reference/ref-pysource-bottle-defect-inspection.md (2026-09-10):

# Referência: Real-time defect identification of products on a conveyor belt (Pysource)

## Fonte

- Título: Real-time defect identification of products on a conveyor belt
- Autor: Sergio Canu (Pysource)
- Data: 2023-02-14
- URL: https://pysource.com/blog (postagem "Real-time defect identification of products on a conveyor belt")
- Tipo: artigo de blog, proof-of-concept de inspeção de garrafas plásticas em esteira

## Pipeline descrita (fonte)

Abordagem básica de visão computacional em vídeo: **object detection + object tracking**.

1. **Object detection**: bounding box em volta da garrafa (e do rótulo), treinado com
   deep learning para reconhecer o objeto; dá posição e classe.
2. **Object tracking**: associa um **ID único** a cada garrafa para evitar conferir a
   mesma garrafa mais de uma vez e manter o histórico.
3. **Classificação de defeito**: cada garrafa é classificada; se danificada, o defeito é
   registrado e a garrafa fotografada (a imagem é salva em pasta).
4. **Database**: defeitos e IDs são gravados em banco SQL; permite estimar o **percentual
   de erro por lote** e monitorar a produção.
5. **Atuação opcional**: pode-se adicionar atividade física (ex.: gate para descartar a
   garrafa defeituosa).

Defeitos considerados na demo: (1) nível de água; (2) defeito/dano do plástico da garrafa;
(3) problema de rótulo (danificado ou ausente); (4) garrafas diferentes ou problemas gerais.

Hardware sugerido pelo autor para processamento não muito pesado: NVIDIA Jetson Nano /
Jetson Xavier, ou laptop com GPU NVIDIA.

Referência acadêmica citada no post: "Research and implementation of machine vision
technologies for empty bottle inspection systems".

## Análise para o Cenário 1 (Inspeção de envase)

Coerências com a nossa proposta (validam o desenho):

- ID único por garrafa + fotografia como evidência + banco + erro por lote/dashboard: é
  exatamente a nossa camada de **rastreabilidade** (PoC-05 registro local e PoC-07
  dashboard/recorrência).
- Multi-class de defeito por item: análogo aos nossos RF-02/03/04 (tampa ausente, mal
  rosqueada, deformidade do corpo).
- Atuação (gate) tratada como acréscimo opcional: coerente com o nosso recorte (sem
  atuação no núcleo; só visibilidade).

Divergências (por que não é o modelo/stack a adotar):

- **Mecanismo de ID**: eles usam object detection + tracking de vídeo para atribuir o ID.
  No nosso caso, com esteira e sensor de presença (E18-D80NK), o **trigger determinístico +
  janela multi-view** é mais simples e exato; tracking de vídeo pode ser registrado como
  alternativa/expansão de referência, não como núcleo.
- **Tipo de defeito**: nível de água e rótulo são alvos deles, fora do nosso escopo
  (nossos requisitos não cobrem rótulo/nível).
- **Hardware**: sugerem GPU/Jetson; nós rodamos no Pi 5 com inferência leve INT8. Mais
  restrito, reforçando a via de modelo leve (teacher-student + one-class leve).
- **Método de classificação**: eles seguem o caminho supervisionado (object detection +
  CNN), que não cobre defeito novo sem dados defeituosos. Complementa (não substitui) a
  nossa direção com one-class (CutPaste) + medição mm determinística.

Estado: CONFIRMED como descrição da fonte; relevância ao nosso dataset SPECULATIVE até
ensaio próprio. Arquivo é referência, não decisão de stack.

## Impacto em decisão

Não fecha decisão. Serve de referência para: (a) o caminho supervisionado (baseline) em
benchmark no nosso dataset; (b) o padrão ID+evidência+banco+dashboard por lote (nosso
PoC-05/07). Combinar com os candidatos já mapeados (one-class leve + medição mm +
professor-aluno) na decisão final de stack.

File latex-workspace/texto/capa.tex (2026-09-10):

\begin{titlepage}
\centering
\vspace*{1.3cm}
{\Large\textbf{FIT: PNAAT 2026}}\\[1.2cm]
{\Huge\bfseries LEVANTAMENTO DE REQUISITOS}\\[0.6cm]
\parbox{0.9\textwidth}{\centering\Large Inspeção Automatizada Multi-View com Rastreabilidade de Anomalias em Linha de Produção}\\[1.4cm]
\begin{tabularx}{0.92\textwidth}{>{\bfseries}p{0.25\textwidth} Y}
Tema: & Cenário 1: Inspeção de envase\\
Grupo: & Soldadinhos do Araripe\\
Integrantes: & \begin{tabular}[t]{@{}l@{}}Luana Teles Alves\\Thiago Nerton Macedo Alves\\Paulo Victor Santos Souza\\Miguel Wagner Galvão Ferreira de Morais\\\end{tabular}\\
Versão: & v1.0\\
Data: & 09/09/2026\\
\end{tabularx}
\vfill
\end{titlepage}

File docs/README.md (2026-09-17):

# Documentação do projeto

Índice da documentação. Cada linha diz o que o documento responde e onde ele está.

## Documento de referência

A fonte de verdade do documento formal é `latex-workspace/`: `main.tex` gera o PDF de Levantamento de Requisitos e `Roteiro.tex` gera o roteiro do vídeo pitch.

O recorte atual é: Cenário 1, inspeção de envase. O núcleo propõe observação multi-view, classificação por domínio, registro rastreável e dashboard usando um nó de observação. O documento não assume controle da velocidade da esteira, atuação física, ejeção, hub central, MQTT ou múltiplos nós como capacidades do núcleo.

## Leitura por objetivo

| Necessidade | Documento |
|---|---|
| Escopo, núcleo e limites do projeto | `escopo.md` |
| Arquitetura proposta e componentes implementados | `arquitetura.md` |
| Catálogo RF-01 a RF-30 e RNF-01 a RNF-21 | `requisitos.md` |
| Fichas detalhadas por domínio | `requisitos/README.md` |
| Dados, schema do registro, taxonomia e consultas | `dados-telemetria.md` |
| Estado do dashboard e das rotas de escrita | `docs/dashboard-site.md` |
| Decisões técnicas, alternativas e critério de fechamento | `DECISIONS.md` |
| Histórico e protocolo das provas de conceito | `pocs/README.md` (fontes de código removidas deste checkout) |
| Correspondência da numeração de PoCs anterior | `pocs/MAPA.md` (histórico) |
| Referências com grau de verificação | `REFERENCIAS.md` |
| Hardware: BOM, pinagem, montagem e limites medidos | `hardware.md` |
| Diagrama de interligação elétrica do núcleo implementado | `diagramas/` |
| Como o dataset foi anotado, com o Label Studio (e o que é dado de instalação) | `reference/uso-do-label-studio.md` |
| Rotulagem assistida por modelo generativo: só criação de dataset, não é runtime | `reference/classificar-gemini.md` |
| Esquemático do trigger (Wokwi ESP32-S3 + sensor) | `reference/esquematico-trigger.md`; zip na raiz `ESP32S3-Trigger.zip` |
| Guia das rotas de trigger, captura, inferência e registro | `operacao-pipeline.md` |
| Replicação do zero, de ponta a ponta (firmware, serviços, ciclo) | `replicacao-ponta-a-ponta.md` |
| Manual de replicação (instalação, execução, verificação) | `../README.md` |

## Fichas de requisitos

| Arquivo | Cobertura |
|---|---|
| `requisitos/01-funcionais.md` | RF-01 a RF-30, incluindo sub-IDs (RF-01.1/1.2, RF-04.1, RF-05.1) |
| `requisitos/02-nao-funcionais.md` | RNF-01 a RNF-21, incluindo RNF-04.1 |
| `requisitos/03-dados-interfaces.md` | DAT-01 a DAT-08 e IF-01 a IF-07 |
| `requisitos/04-atuacao-seguranca.md` | Atuação, controlabilidade, observabilidade e segurança (expansão) |
| `requisitos/05-hardware-ml.md` | Rig, elétrica, iluminação, dataset e modelos |
| `requisitos/06-operacao.md` | Operação, manutenção, documentação e reprodutibilidade |

## Provas de conceito

| Caminho | Conteúdo |
|---|---|
| `pocs/README.md` | Matriz canônica das PoCs e estado verificado da execução de referência |
| `pocs/MAPA.md` | De-para entre os diretórios da geração anterior e as PoCs entregues |
| `pocs/poc02_classificacao/` | Protocolo da PoC-02 (classificação de tampa) |
| `pocs/poc08_preproc/` | Protocolo da PoC-08 (pré-processamento e geometria) |
| `pocs/03-sincronizacao-fisica/CALIBRACAO-DELAY.md` | Calibração do atraso trigger → captura e do casamento da velocidade da esteira (expansão; protocolo, fontes removidas deste checkout) |
| `pocs/01-classificador-topo/`, `pocs/02-deformidade-lateral/`, `pocs/03-sincronizacao-fisica/`, `pocs/04-correlacao-multi-no/`, `pocs/05-integracao-dados/`, `pocs/06-resiliencia/`, `pocs/07-atuacao-confirmada/` | Fichas da geração anterior, preservadas como histórico e expansão |

## Referência e design

| Caminho | Conteúdo |
|---|---|
| `reference/` | Notas de referência, medições próprias e caracterização de componentes |

## Referências externas verificadas

- `reference/ref-pysource-bottle-defect-inspection.md`: inspeção de defeito de garrafa em esteira (Pysource): ID único, banco e dashboard por lote. Referência, não decisão de stack.
- `reference/ref-eca-efficientdet-packaging-bottle-defects.md`: detecção de defeito de tampa e rótulo com ECA-EfficientDet (mAP 99,16%).
- `reference/ref-jarvis-bits-bottle-defect-detection.md`: Mask-RCNN com CNN (87,7% e 72%), recuperada como piso de comparação.
- `reference/ref-e18-d80nk-sensor.md`: caracterização do sensor candidato de presença.
- `reference/limiares-tampa-fonte-e-calibracao.md`: por que os limiares da tampa exigem calibração empírica (D-24).
- `reference/medicao-vies-elipse-geometria.md`: medição própria do viés do ajuste de elipse.

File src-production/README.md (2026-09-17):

# src-production: o produto

Pacote `pnaat-inspecao`. Esta arvore e o **entregavel**: codigo, testes, esquema do hub, firmware, o site
estatico e o pipeline de treino que produz o detector. As PoCs da geração anterior foram removidas
deste checkout; documentos sob `docs/pocs/` permanecem como histórico, sem fonte executável nesta
árvore. `dataset/TRABALHO/` e `dirty-workspace/` guardam a arvore de trabalho antiga: **nao e importada em runtime**.

## Modulos

| Arquivo | Responsabilidade |
|---|---|
| `dominio.py` | Dominios, vocabulario de classes por dominio (D-28), evidencia tipada e o contrato do evento |
| `decisao.py` | Decisao por vista (D-30): o classificador decide, a geometria e auxiliar, o fallback roteia e nunca aprova |
| `conformidade.py` | Regra por dominio (D-04/D-29): defeito em qualquer vista reprova, aprovacao exige o rig completo, discordancia preservada |
| `captura.py` | Monta as vistas do mesmo `item_id`; verificacao de posicionamento fail-closed (NCC + tolerancia em px) |
| `identidade.py` | Formato e geracao do `item_id` (`<lote>-<sequencia>`), com sequencia ancorada no banco |
| `registro.py` | Persistencia idempotente por `item_id`; recusa evidencia divergente |
| `painel.py` | As consultas analiticas de `docs/dados-telemetria.md` secao 3, somente leitura |
| `orquestracao.py` | Pipeline unica (captura -> decisao -> conformidade -> registro) e entry point |
| `classificador.py` | Classificador da tampa (extrator congelado + linear) atras do protocolo da D-30; CORPO devolve `None` |
| `classificador_artefato.py` | Consumidor do artefato `.npz` medido (D-37) |
| `classificador_yolo.py` | Consumidor do PACOTE de detector (YOLO) na cadeia: contrato verificado, decisao sem silencio |
| `preparo_detector.py` | Pre-processamento do detector: recorte, rotacao e contrato, a mesma funcao do treino |
| `pacote_detector.py` | Formato do pacote (peso + contrato + metadados + checksums), verificado dos dois lados |
| `fonte_gatilho.py` | Le o CSV de eventos de gatilho da bancada e persiste pela API do registro (RF-01.1) |
| `ingerir_serie.py` | Ingere uma serie de captura do rig como item do registro |
| `mapeamento_rig.py` | Mapa declarado camera -> vista (sem ele a ingestao para) |
| `apresentacao.py` | Relatorio HTML estatico a partir das consultas do painel (o elo 'apresenta') |
| `api.py` | API HTTP do hub; serve o site estatico na mesma origem |
| `preprocessamento.py` | Padrao de pre-processamento do projeto (recorte, rotacao, flat-field, CLAHE, elipse); consumido pela cadeia do detector via `preparo_detector.py` |
| `scorers.py` | Scorers do harness OOD; carregado por `avaliacao_ood.py --scorer <arquivo>:<funcao>` (import por caminho, nao por nome de modulo) |
| `avaliacao_ood.py` | Harness de avaliacao fora de distribuicao (CLI), com baseline e scorer externo |
| `esquema.sql` | Esquema do hub, com as invariantes no banco (o topo nunca decide; decidir exige dominio) |

## Fiacao: quem consome o que

Modulo sem consumidor nao e bug por si; consumidor NAO DECLARADO e. Esta tabela e o contrato de
fiacao de cada modulo que ja foi lido como "orfao" numa auditoria:

| modulo | quem chama | como |
|---|---|---|
| `preprocessamento.py` | `preparo_detector.py`, `classificador_yolo.py`, `orquestracao.py`, `pacote_detector.py` | import direto |
| `scorers.py` | `avaliacao_ood.py` | import por caminho (`--scorer src-production/scorers.py:funcao`); grep estatico nao enxerga |
| `fonte_gatilho.py` | operador/CLI da bancada (RF-01.1) | ingestao do CSV do gatilho; nao e chamado pela API |
| `captura.py` | `orquestracao.py` | import direto (fonte de bancada; camera ao vivo quando o rig existir) |
| `/api/rig-serie/` | operador, sem cliente no site | endpoint de operador: `curl -H "X-Token: $TOKEN" <origem>/api/rig-serie/<serie>/<arquivo>` |
| contrato v0 | nada | geracao v0 substituida; fora do produto e sem teste no repo |

## Frontend do site

O frontend estatico vive em `site/` e e servido pela API na mesma origem. O default de `api.py` aponta
para esse diretorio; use `--site` apenas para sobrescrever o caminho.

## A cadeia de treino, de ponta a ponta

```
anotacao humana (Label Studio)
  -> treino/exporta_anotacoes.py        CSV canonico + recibo de frescor
  -> treino/guarda_frescor.py           aborta se o LS avancou desde o export
  -> treino/monta_v1_detector.py        dataset: split POR ITEM, quase-duplicata (dHash), ROI
  -> treino/treina_v1.py                base limpa externa + ajuste fino no nosso dominio
  -> treino/avalia_por_dominio.py       mAP por dominio e classe
  -> treino/avalia_limiares.py          P/R/F1 por limiar
  -> treino/calibra_limiar_val.py       limiar por classe NA VALIDACAO -> contrato
  -> treino/kfold_por_item.py           metrica de aceitacao (listas disjuntas por item)
  -> treino/pacote_entrega.py           PACOTE: peso + contrato + metadados + checksums
  -> classificador_yolo.py              consome o pacote na cadeia (decide)
  -> orquestracao.py                    captura -> decisao -> conformidade -> registro
  -> painel.py / apresentacao.py / api.py   as consultas e a vitrine
```

O elo treino→inferencia e o **pacote**, verificado dos dois lados:

```text
<pacote>/<peso>.pt             peso torch do detector (nunca desserializado fora do predict)
<pacote>/preprocessamento.json contrato de pre-processamento (ROI/rotacao/imgsz/classes/limiares)
<pacote>/metadados-treino.json model-meta.json do run que produziu o peso
<pacote>/modelo.json           manifesto do pacote (hashes declarados, limitacoes)
<pacote>/SHA256SUMS            inventario fechado
```

## O que faz treino e inferencia serem a MESMA coisa

`preparo_detector.py` e a unica definicao de recorte, rotacao e leitura de contrato; o montador de
dataset e o consumidor da cadeia usam **a mesma funcao**. Antes eram duas regras (PIL no treino,
outra formula na inferencia): medido em 2026-09-15, 1 px de deslocamento e 0,17 de F1 macro.

Campos que o contrato precisa declarar, e por que cada um e guarda:

| Campo | Por que existe |
|---|---|
| `roi_por_camera` | recorte declarado por camera; sem ele o modelo ve outra imagem |
| `rotacao_graus` + `orientacao_entrada` | `quadro_ja_orientado` (a fonte entrega como no treino) ou `rotacionar_no_consumo`. **Ambiguidade e erro**: adivinhar troca 90 por 0 em silencio |
| `vista_por_camera` | qual camera produz qual vista; vista repetida em duas cameras e erro |
| `imgsz_treino` | a resolucao do treino; limiar calibrado em outro tamanho nao vale |
| `limiares_por_imgsz[c].calibrado` + `fonte` | limiar sem fonte e recusado pelo preparo (`preparo_detector.py` exige `calibrado`) |
| `classes` | por NOME; a ordem do indice no `.pt` e a identidade da classe |
| `modelo.sha256` | contrato de um peso nao vale para outro |
| `fingerprint` | hash canonico dos campos que mudam a predicao; arquivo editado a mao nao abre |
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

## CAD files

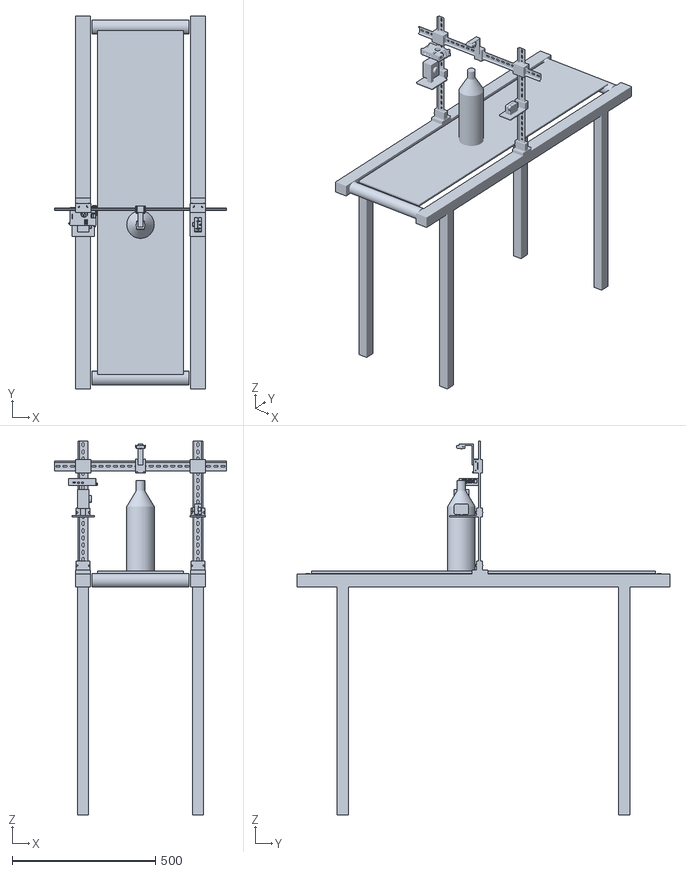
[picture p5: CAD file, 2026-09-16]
cad-produto/00-produto/composicao-esteira/composicao.stl
600.0 x 1300.0 x 1302.9

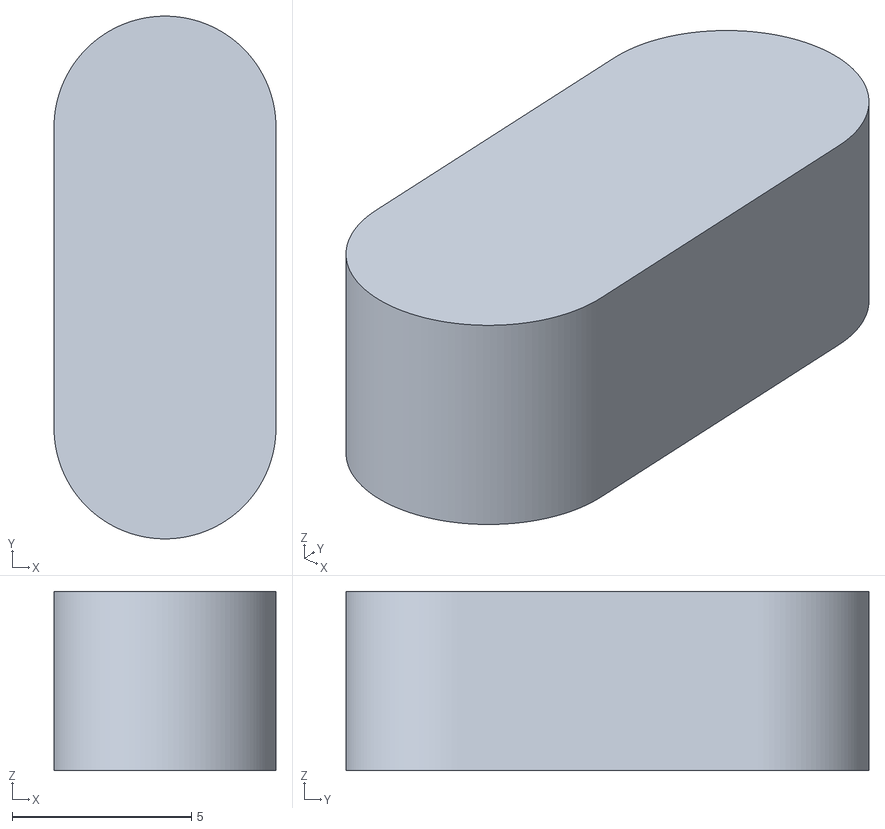
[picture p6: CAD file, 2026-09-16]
cad-produto/01-estrutura/ChavetaA.stl
6.20 x 14.6 x 5.00

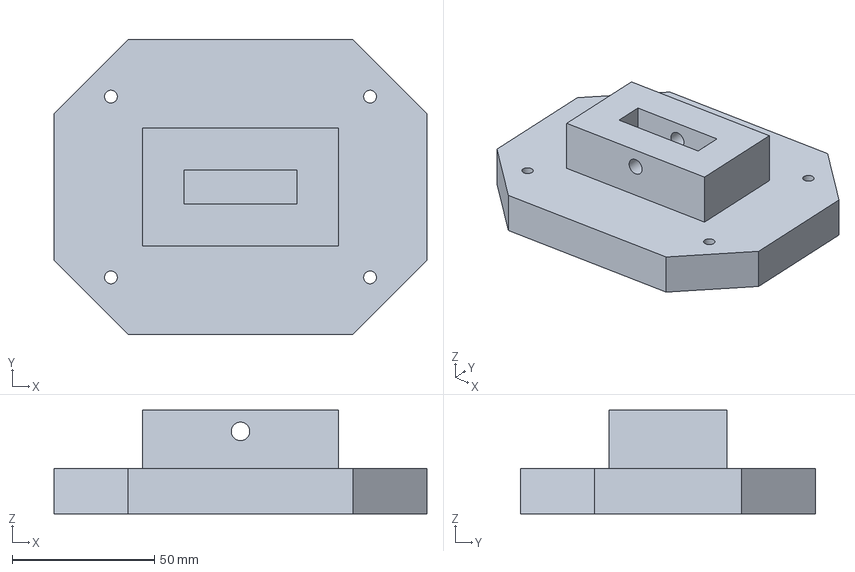
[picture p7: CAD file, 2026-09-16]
cad-produto/02-impressao/base-trilho/base-somente.step
131.0 x 103.5 x 36.5 mm

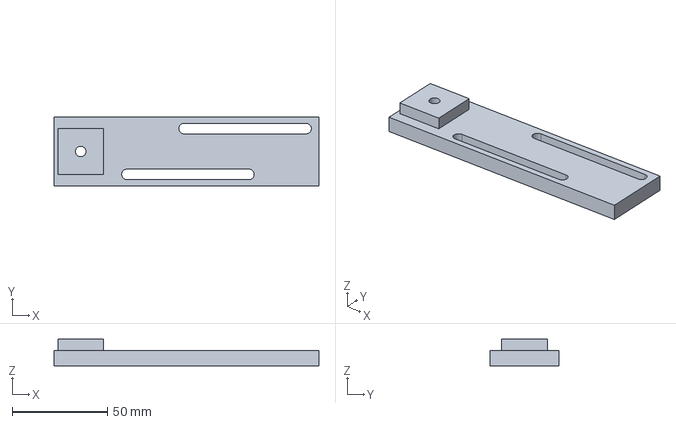
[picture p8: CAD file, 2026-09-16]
cad-produto/02-impressao/camera-lateral/DistanceSlider_M5Tab.step
139.0 x 36.0 x 14.0 mm

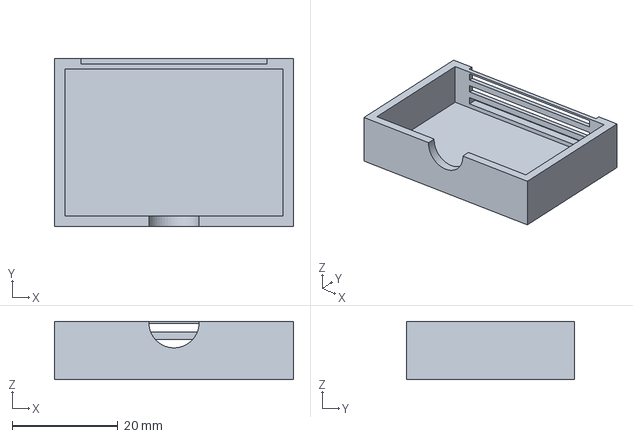
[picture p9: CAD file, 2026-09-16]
cad-produto/02-impressao/case-esp32cam/esp32cam-case-din.step
45.3 x 31.8 x 11.0 mm

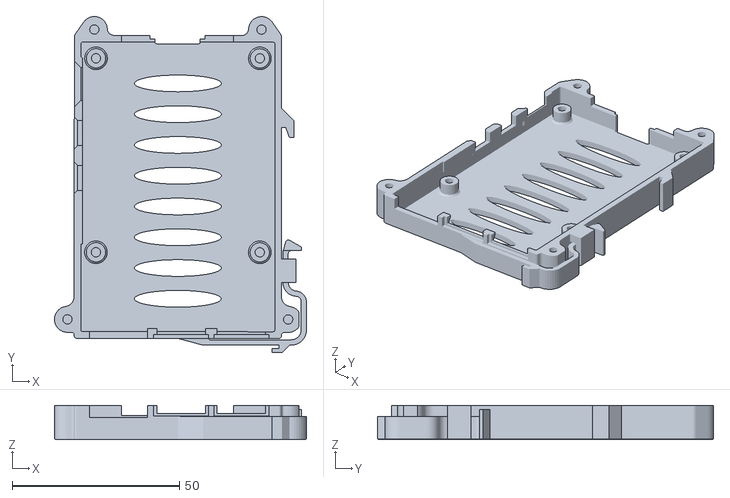
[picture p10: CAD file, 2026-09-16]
cad-produto/02-impressao/case-pi-din/pi5-din-bottom-side.stl
75.4 x 100.5 x 10.3

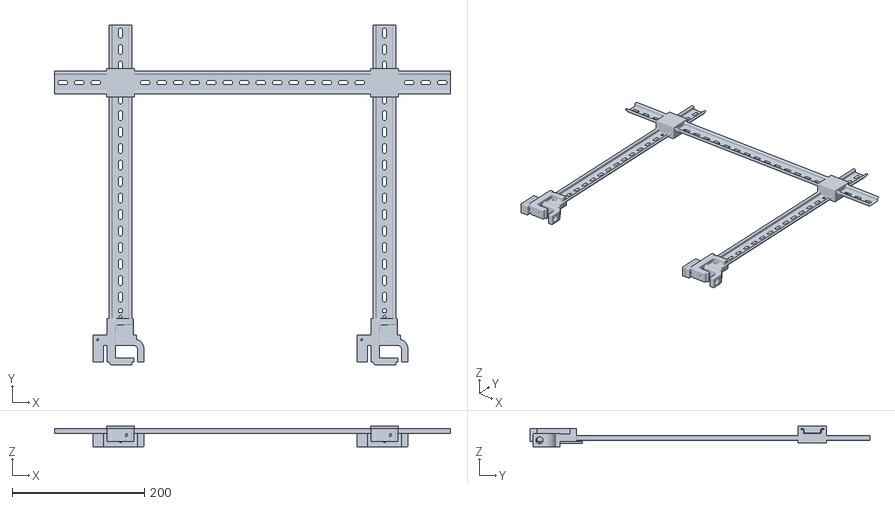
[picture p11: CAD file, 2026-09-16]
cad-produto/00-produto/conjunto-portico.stl
600.0 x 515.5 x 31.5

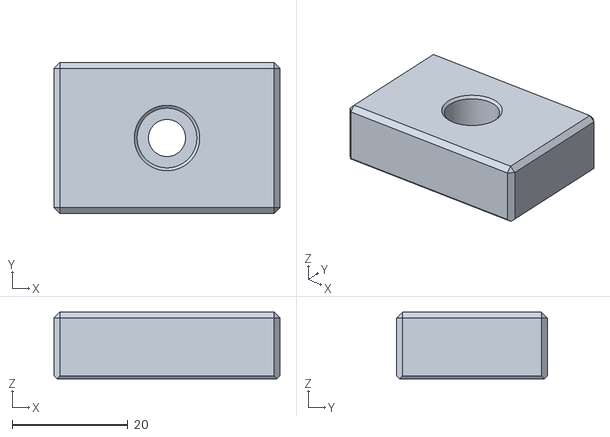
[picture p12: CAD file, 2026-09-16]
cad-produto/01-estrutura/B_BRACKET.stl
39.0 x 26.0 x 11.5

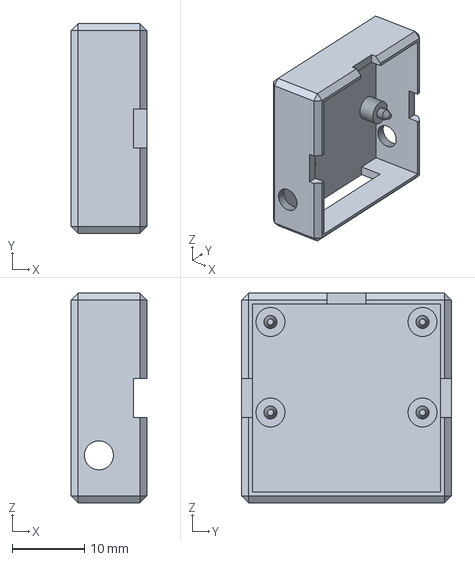
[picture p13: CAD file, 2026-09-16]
cad-produto/02-impressao/camera-lateral/Housing_SOURCE_REFERENCE.step
10.5 x 29.0 x 29.0 mm

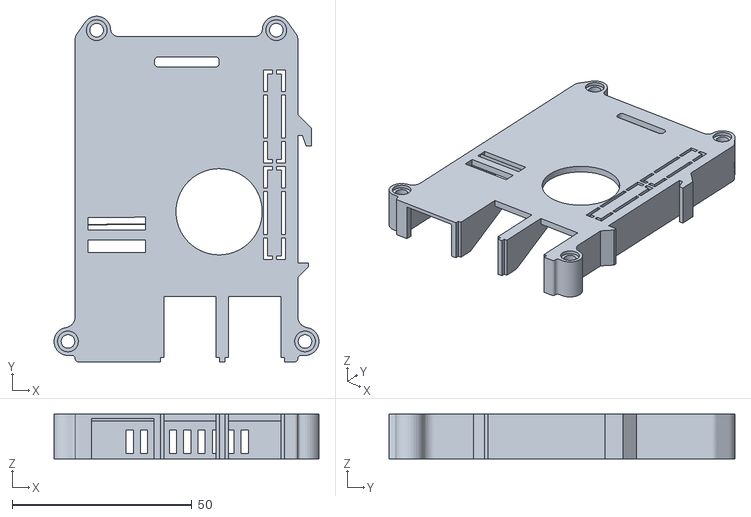
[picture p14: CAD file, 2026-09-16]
cad-produto/02-impressao/case-pi-din/pi5-din-topside.stl
73.8 x 96.3 x 12.5

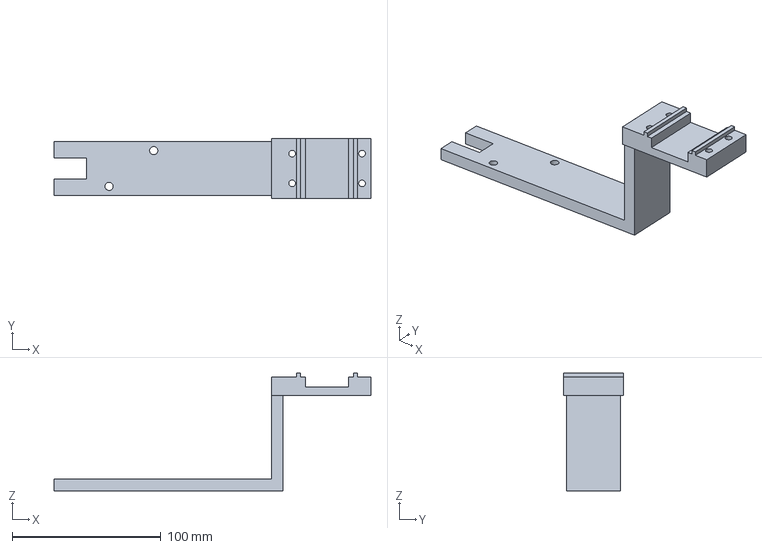
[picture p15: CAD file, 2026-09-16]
cad-produto/02-impressao/camera-lateral/ClampFront_Arm.step
213.0 x 40.0 x 79.0 mm

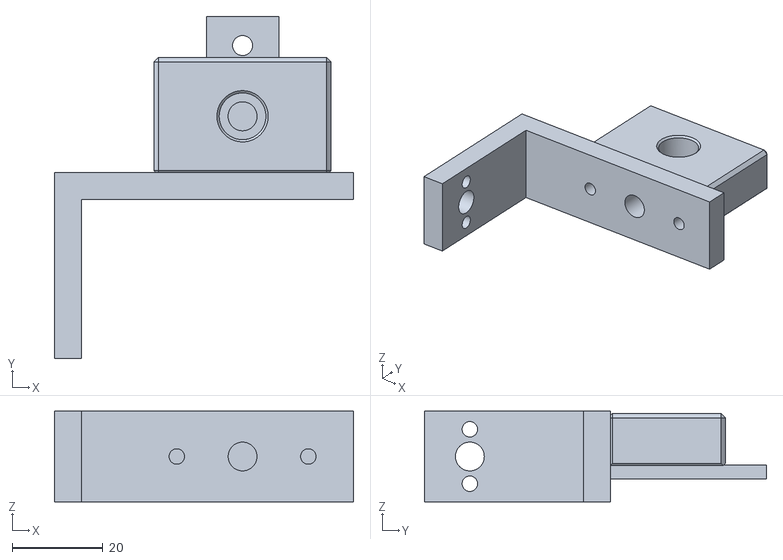
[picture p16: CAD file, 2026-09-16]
cad-produto/01-estrutura/PecaDuplaPlataformasOFICIALB.stl
66.0 x 75.4 x 20.0

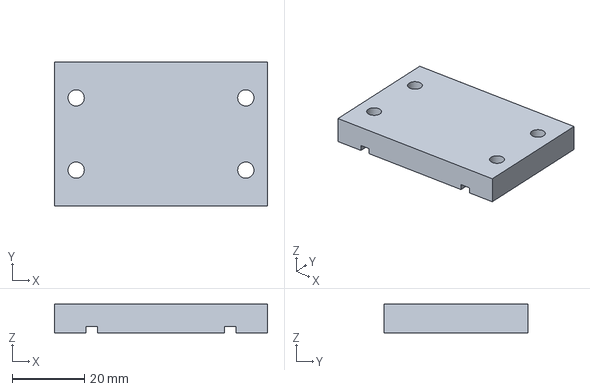
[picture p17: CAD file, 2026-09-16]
cad-produto/02-impressao/camera-lateral/ClampRear.step
59.0 x 40.0 x 8.00 mm

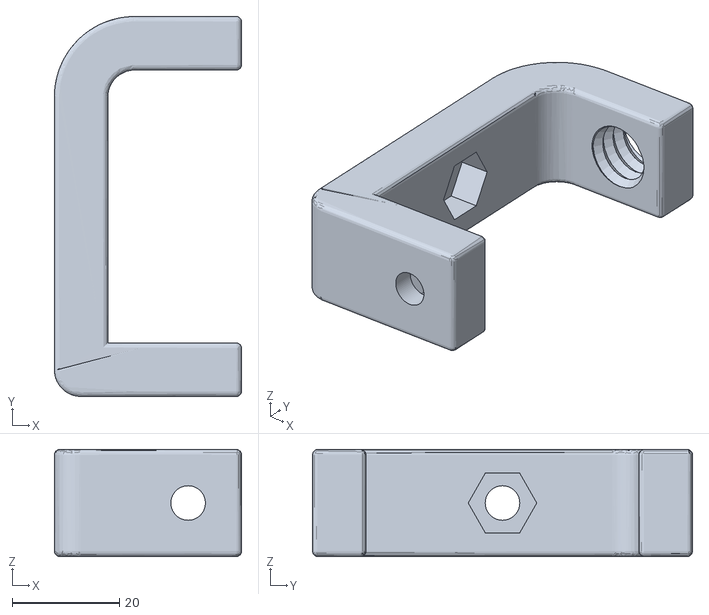
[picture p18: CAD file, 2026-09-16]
cad-produto/01-estrutura/A_CLAMP.stl
35.0 x 71.0 x 20.0

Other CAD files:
cad-produto/02-impressao/base-trilho/base-bracket.step
cad-produto/02-impressao/camera-lateral/Cover_SOURCE_REFERENCE.step
cad-produto/01-estrutura/JuncaoA.stl
cad-produto/01-estrutura/A_BRACKET.stl
cad-produto/01-estrutura/A_PECA.stl
cad-produto/01-estrutura/B_CLAMP.stl
cad-produto/01-estrutura/B_PECA.stl
cad-produto/01-estrutura/ChavetaB.stl
cad-produto/01-estrutura/ClampFunctionalSource.stl
cad-produto/01-estrutura/ClampFunctionalSourceB.stl
cad-produto/01-estrutura/JuncaoB.stl
cad-produto/01-estrutura/MontanteA.stl
cad-produto/01-estrutura/MontanteB.stl
cad-produto/01-estrutura/ParafusoTravaH_A.stl
cad-produto/01-estrutura/ParafusoTravaH_B.stl
cad-produto/01-estrutura/ParafusoTravaV_A.stl
cad-produto/01-estrutura/ParafusoTravaV_B.stl
cad-produto/01-estrutura/PecaDuplaPlataformasOFICIAL.stl
cad-produto/01-estrutura/Travessa.stl
cad-produto/02-impressao/base-trilho/base-bracket.stl
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

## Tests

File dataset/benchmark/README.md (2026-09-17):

# benchmark/: terceiro, para comparar metodo

`mvtec/` (MVTecAD, ~5,0 GB) e referencia publica: serve para responder "o pipeline esta bom?" sem
depender do nosso dado. So o subconjunto `bottle/` e usado.

Nao versionado. Registre a versao do benchmark quando reportar numero, senao a comparacao entre
rodadas nao vale nada.

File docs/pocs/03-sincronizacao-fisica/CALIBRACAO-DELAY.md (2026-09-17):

# Calibração: atraso trigger → captura e casamento da velocidade

Procedimento de bancada do sistema `code-workspace/src/pocs/expansao_sincronizacao/` + `code-workspace/scripts/calibrar_delay_trigger.py`.
Status: sistema entregue e verificado em 2026-09-14 (ver seção de evidências).

## O problema, em uma linha

O sensor está a `d` mm do centro da ROI da câmera. Se a captura disparar no instante do trigger,
a garrafa ainda está `d` mm antes; se disparar tarde, ela já passou. O instante certo é
`τ* = d / v` — e nem `v` nem o mm/pixel são conhecidos a priori.

## Fase 0 — antes de medir (não pular)

| # | Item | Critério |
|---|---|---|
| 0.1 | Medir `d` com régua/paquímetro: do **plano de detecção** do E18-D80NK ao **centro da ROI** da câmera | número em mm registrado no comando |
| 0.2 | **O trigger tem de estar dentro do campo de visão da câmera** | se o item nunca aparecer inteiro no quadro, não há posição para medir |
| 0.3 | Câmera com exposição, foco e WB **travados** | sem auto-exposição variando durante a rajada |
| 0.4 | Iluminação fixa e registrada | mesma configuração entre passagens |
| 0.5 | Esteira vazia para a referência | o instrumento grava `~/poc03/referencia-esteira-vazia.jpg` |
| 0.6 | Supervisor da PoC-01 ativo (dono único da serial) | log recebendo `EV OPEN` |
| 0.7 | Nenhum outro processo com `/dev/videoN` aberto | câmera tem um leitor |

A janela da rajada deve cobrir o cruzamento: `--janela ≥ τ*` (com folga). Janela curta demais
transforma a medição em extrapolação — e o relatório avisa quando isso acontece.

## Fase 1 — rodar a calibração (uma vez por vista)

```bash
cd <TCC_HOME>
make calibrar-delay-bancada DIST=150 PASSOS=5                 # vista padrão: "principal"
# ou, com o nome da vista (cada câmera tem o seu próprio atraso):
<TCC_HOME>/.venv/bin/python code-workspace/scripts/calibrar_delay_trigger.py \
    --fonte log --vista topo --distancia-mm 150 --passagens 5 --janela 2.2 --aplicar
```

Passe 5 itens. Cada `EV OPEN` abre uma rajada de `--janela` segundos; os quadros são amostras
`(τ, offset)` e a reta sai dos quadros de todas as passagens.

## Fase 2 — ler o veredito

**PASS** exige: `n ≥ 5` amostras, `r² ≥ 0,9`, resíduo ≤ `--tolerancia-mm` e `τ* > 0`.
Só com PASS o `delay.json` é gravado. O relatório traz `τ*`, velocidade medida, escala mm/px,
resíduo, contagem de descartes e o envelope de velocidade.

Avisos que não devem ser ignorados:

- **`τ*` fora da janela observada** → número extrapolado: aumente `--janela` e recalibre.
- **`intercepto não negativo`** → sinal do offset ou distância declarada errados.
- **Ensaio reprovado com corte na borda** → suspeita de trigger fora do campo de visão.
- **`descartes: cortado_na_borda`** → normal no início da rajada (o item ainda está entrando);
  só é problema quando nenhum quadro válido sobra.

## Fase 3 — o envelope: que velocidade a esteira pode ter

O teto é o **menor** entre três limites, todos medidos:

| Limite | Fórmula | Com os números do rig |
|---|---|---|
| Orçamento de captura | `passo / (vistas × tempo_por_vista + rearme + margem)` | 80 / (3×0,077 + 0,5 + 0,02) = **107 mm/s** |
| Re-armadura do trigger | `passo / 0,5 s` (ARM_MS=500, GUARD_MS=500) | 80 / 0,5 = 160 mm/s |
| Janela de presença | `comprimento / 0,1 s` (STABLE_READS=5 × DEBOUNCE_MS=20) | 60 / 0,1 = 600 mm/s |

Com passo de 80 mm, **manda o orçamento de captura: ~107 mm/s**. Para correr mais rápido é preciso
aumentar o passo (mais espaço entre itens) ou reduzir o número de vistas — subir a velocidade sem
mexer nisso faz o trigger perder garrafas.

## Fase 4 — usar o atraso

`~/poc03/delay.json` guarda **uma entrada por vista** (`tau_s`, `distancia_mm`, velocidade medida,
escala, resíduo, contagens). O capturador lê com `carrega_delay()` + `tau_da_vista(nome)` e agenda a
captura `tau_s` após cada borda de trigger. Vista não calibrada → `KeyError` (não há default).

## Verificação sem hardware

```bash
make calibrar-delay              # física pura contra verdade injetada
make calibrar-delay-integracao   # caminho do ensaio: log isolado + câmera sintética
```

O ensaio de integração usa um log de ensaio próprio (`~/poc03/log-ensaio.log`, no formato do
supervisor) — **nunca** o log real — e cobre: duas vistas acumulando no `delay.json`, o caso
infeasível (janela menor que τ\*, que tem de reprovar) e o consumo fail-closed.

Evidências de 2026-09-14:

| Ensaio | Resultado |
|---|---|
| Verdade conhecida | r² 0,9998, resíduo 1,44 px, erro 0,1% em τ\* e v |
| Régua mentida (300 mm declarados, 150 reais) | erro 99,9% → reprova e não aplica |
| Caminho do ensaio, vista topo (d=150) | erro 0,0% contra verdade, 114 amostras em 2 passagens |
| Caminho do ensaio, vista lateral1 (d=220) | erro 0,0%, τ\*=2200 ms, sem apagar a vista topo |
| Caso infeasível (d=300, janela 1,2 s) | reprova, exit 1, nenhum delay aplicado |
| Suíte do repositório | 112 passed (estado 18/09) |

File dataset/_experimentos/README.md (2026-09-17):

# _experimentos/: saida de experimento, entrada rejeitada, controle

Saida que nao virou dado. Serve para lembrar o que ja foi tentado e por que nao entrou.

- saidas de modelo (ex.: PatchCore) que nao foram promovidas;
- entradas rejeitadas na validacao de par (bbox/mascara/isolamento);
- controles: perturbacao conhecida que **nao** e defeito real, usada para provar reacao do modelo
  (ver `TRABALHO/` para o gerador).
- `_EXPERIMENTO-ABSTENCAO`, `_EXPERIMENTO-DOMINIO-*`, `_COMPARACAO-EXTRATORES`: registros de
  decisao com numero medido.

Nao versionado. Se um experimento virar dado, ele e promovido para `nosso/` ou `anotacao/` com
movimentacao registrada em `REORGANIZACAO-<data>.csv`.

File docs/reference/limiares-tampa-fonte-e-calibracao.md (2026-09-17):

---
tags: [type/reference]
aliases: []
lead: "D-24: limiares da tampa: o 2° publicado é de outra grandeza (ângulo do chuck, não tilt da tampa); calibração empírica é obrigatória."
created: 2026-09-11
modified: 2026-09-11
review_status: reviewed
---

# Limiares da tampa: fonte primária ou calibração empírica (D-24)

Data: 2026-09-11. Motivo: D-24 exige que todo limiar de aceitação tenha **fonte primária**
(`arquivo:linha`) ou **validação empírica registrada**. Estado anterior: `tilt_incerto=2,0°`,
`tilt_reprova=4,0°` e `altura_ausente_px=3,0` estavam no código **sem fonte**.

## Varredura declarada (regra 6 do protocolo)

Buscado em: `docs/reference/`, `docs/design/`, `docs/pocs/` (por nome e por conteúdo) e na web
(7 consultas sobre padrão de tampa/PCO 1881, ISBT, inspeção de tampa solta e detecção de tampa torta).
Status: `P` = primária/industrial com vínculo verificável · `S` = secundária/índice · `B` = guia de prática.

## O que existe de número publicado (e por que quase nada transfere)

| Fonte | Número | Status | Transfere para o nosso tilt? |
|---|---|---|---|
| Delta El Nile: *Preform/Closure Defect Manual* (PDF industrial), entrada CRITICAL "Application angle deviation (chuck approach > 2° tilt)", citando Bevcap Application Angle Standards §5.2 e PMMI/OMAC Capping §3.4 | **máx. 2° do vertical no momento do contato de aplicação** | `P` | **NÃO**: é o **ângulo de aproximação do chuck** (máquina), não o tilt final da tampa medido por visão. Grandezas diferentes. |
| Delta El Nile: bandas de referência **PCO 1881 / CSD, enchimento ambiente** | application torque 13-19 in·lbs · **application angle 760°-800°** · removal 5-14 in·lbs · strip > 25 in·lbs · selo ≥ 100 psi | `P` | **NÃO direto**: ângulo de **rotação** da aplicação e torque: exigem o lado da máquina/torquímetro, não visão. |
| Delta El Nile: mesmo manual, "Insufficient application torque (loose caps)" e "PCO 1881: 14 in-lbs minimum" | **14 in·lbs mínimo** de break-torque | `P` | **NÃO**: definição de "frouxa" por torque, não por ângulo. |
| **ISBT**: *Plastic Bottle Closure Qualification Test Manual* (PTC-00019, abr/2023); *Plastic Closure Ovality Guideline* (PTC-00022, dez/2024); *Capping and Inspection Equipment for Glass and Plastic Containers* (PTC-00012, mai/2014) |: | `P` (existência e ementa) | São os documentos normativos do domínio; a ISBT declara que os ensaios avaliam o **sistema de embalagem** e que **fornecedor e engarrafador devem acordar as especificações** → **não há tolerância angular universal publicada** para "tampa torta". |
| MDPI *Eng. Proc.* (2023), *Machine-Vision-Based Plastic Bottle Inspection* | 95% para tampa (ROI + Harris corners + linha de referência entre cantos extremos; **distância comparada com o limiar conhecido da tampa assentada**) | `S` | **É o precedente de MÉTODO**, não de número: o limiar vem de uma **referência de tampa assentada**: exatamente o caminho de calibração empírica. |
| Xie et al. (2017, IEEE ICCC): inspeção de PET por distância entre support ring e tampa | **99%** para tampa solta em PET | `S` | Método (medição de distância com limiar): reforça calibração, não dá o número. |
| Kumchoo & Chiracharit (2018): tampa solta e anel em vidro | **87%** | `S` | Referência de piso de desempenho em vidro. |
| A*STAR (2021): sensor capacitivo de integridade de tampa | detecta uncapped e **tilted**; LOD ~0,11 cm (contato) / 0,23 cm (não-contato) | `S` | Outro princípio físico; útil como ordem de grandeza do deslocamento detectável. |
| lekapackline: guia industrial de problemas de rosqueamento | "a cocked or tilted cap describes its angled position… **the angle alone does not prove the exact thread condition**"; "visible gap or abnormal cap height… is **not** a torque measurement" | `B` | **Sustenta a D-23**: tilt sozinho não conclui; o topo verifica dimensão/assentamento. |

## Veredito para D-24

1. **`tilt_incerto=2,0°` e `tilt_reprova=4,0°` não têm fonte transferível.** O único "2°" publicado é o
   **ângulo de aproximação do chuck**: outra grandeza. Adotá-lo como limite de tilt da tampa repetiria
   o erro do NCC (número de uma medição usado para descrever outra). Ficam como **parâmetros
   provisórios**, e **não** como critério de aceitação.
2. **`altura_ausente_px=3,0` não tem fonte alguma** (nem provisória): é limiar puramente empírico.
3. **Não existe tolerância angular universal** para "tampa mal rosqueada": a própria ISBT condiciona a
   especificação ao **sistema de embalagem acordado** entre fornecedor e engarrafador. Logo, **a única
   rota defensável é a calibração empírica no nosso conjunto**, com o limiar derivado de uma
   **referência de tampa assentada** (precedente MDPI/Xie), registrado com `n`, método e procedência.
4. O que **existe** e pode ser citado como requisito de sistema (não como nosso limiar): janela de
   torque/aplicação PCO 1881 do manual industrial e os manuais ISBT (PTC-00019 / PTC-00022 / PTC-00012).

## Protocolo de calibração (pré-registro, D-24b)

Script: `workspace/scripts/calibrar_limiares_tampa.py` (+ `tests/test_calibrar_limiares_tampa.py`).
Método: varredura determinística de candidatos, escolha pelo **índice de Youden** (sens + espec − 1) com
desempate por maior margem; saída com sensibilidade/especificidade e **limite inferior do IC95**, zona
cinzenta, `n` por classe, hash do CSV de entrada e data.

1. Medir a grandeza (tilt por vista lateral; altura/assentamento pelo topo) em itens rotulados.
2. **Bloco A** (primeira metade, aleatorizada): escolher o limiar e **congelar** (grava `limiares.json`).
3. **Bloco B** (segunda metade): validar o limiar congelado: o número do bloco B é o resultado.
4. Reportar: limiar, sens/espec com LB95, zona cinzenta e sobreposição.
5. Se a **zona cinzenta for larga** (as distribuições se sobrepõem), o veredito honesto é que **tilt
   sozinho não separa** `mal_rosqueada`: e a decisão passa a exigir a segunda lateral e/ou o check
   dimensional do topo (D-23), nunca um limiar apertado para maquiar o resultado.
6. `n` mínimo do script: 20 por classe para emitir limiar; abaixo disso ele **recusa** e reporta quanto falta.

## Consequências imediatas

- Recursos utilizados (números do manual industrial, ISBT, precedentes de método) entram em
  `docs/REFERENCIAS.md` com status `P`/`S`/`B` e a marca de "não transfere" onde for o caso.
- `politica_tampa.py`: os três limiares ficam marcados como **provisórios** até o bloco A da calibração.
- Nenhum relatório da PoC-02 pode citar esses valores como critério atendido antes da calibração.

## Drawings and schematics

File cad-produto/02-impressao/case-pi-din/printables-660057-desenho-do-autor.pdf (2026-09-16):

## Rail

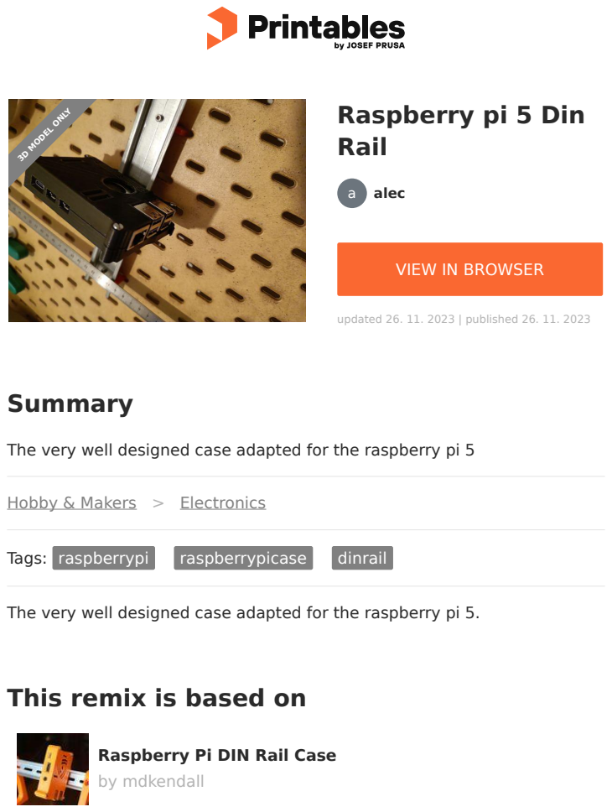
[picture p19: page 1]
Summary; Hobby & Makers; Electronics; Tags: raspberrypi; raspberrypicase; dinrail; by mdkendall; alec; updated 26. 11. 2023 | published 26. 11. 2023; 3D MODEL ONLY

Raspberry pi 5 Din

VIEW IN BROWSER (https://printables.com/model/660057-raspberry-pi-5-din-rail)

The very well designed case adapted for the raspberry pi 5

The very well designed case adapted for the raspberry pi 5.

This remix is based on

Raspberry Pi DIN Rail Case (https://printables.com/model/133497-raspberry-pi-din-rail-case)

## Model files

License

This work is licensed under a
Creative Commons (4.0 International License)

Attribution⁻ShareAlike (http://creativecommons.org/licenses/by-sa/4.0/)

✖ | Sharing without ATTRIBUTION
✔ | Remix Culture allowed
✔ | Commercial Use
✔ | Free Cultural Works
✔ | Meets Open Definition

raspberry-pi-5-din⁻topside.stl

raspberry-pi-5-din⁻rail-bottom⁻side.stl

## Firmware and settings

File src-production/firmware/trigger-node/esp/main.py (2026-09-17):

"""PoC-01 no ESP32 v4: trigger com E18-D80NK: log legivel, armado seguro e guarda anti-duplicacao.

Correcoes vindas da bancada (v3):
  1. ARMADO SEGURO: apos o aquecimento, so arma quando a linha fica estavel em REPOUSO (nivel 1)
     por ARM_MS continuos. Isso elimina a janela espuria no boot (a linha nasce LOW por alguns ms).
  2. GUARDA ANTI-DUPLICACAO: depois de um CLOSE, nova presenca so abre janela se (a) passou
     GUARD_MS E (b) a linha voltou ao repouso entre as duas. A guarda sozinha nao bastava: o
     mesmo objeto que continuava na frente reabria janela depois de um CLOSE por flicker. Um
     SUPPRESSED registra o motivo (guarda ou presenca_continua).
  3. LOG IDENTIFICAVEL: todas as linhas saem como `EV <evento> campo=valor ...` (nivel, n, tempos),
     tanto na serial quanto em /poc01_events.csv. O host interpreta esse formato.

Eletrica: bege = +5V, azul = GND, preto = sinal em P27 (PULL_UP). 0 = objeto, 1 = repouso.
Instalar como main.py faz o firmware iniciar sozinho a cada reset/boot.
"""
from machine import Pin
import time

PRESENCE_PIN = 27          # pino normativo; validar tensão/condicionamento no sensor físico
PINOS_CANDIDATOS = (33, 32, 25, 14, 13, 4)   # entrada com pull-up e livres na placa;
                                             # P27 fica FORA: e o proprio pino do sensor
                                             # (reportado em nivel=) e incluí-lo gerava
                                             # evento falso de "descoberta de fiacao"
CAPTURE_OUT_PIN = 26
DEBOUNCE_MS = 20
STABLE_READS = 5          # leituras LOW para abrir (5 x 20 ms = 100 ms)
MISS_READS = 5            # leituras HIGH para fechar
# CAPTURE_OUT sobe no OPEN e desce no CLOSE: o pulso dura a presenca do item.
# (Havia uma constante WINDOW_MS declarada como "largura do pulso" e nunca usada.)
WARMUP_MS = 1000          # ignora o transitorio de boot
ARM_MS = 500              # repouso continuo exigido para armar (era ARM_READS=10 x
                          # 20 ms = 200 ms, apesar do comentario dizer 500 ms)
GUARD_MS = 500            # janela morta apos cada fechamento
LOG_PATH = "poc01_events.csv"
LOG_MAX_BYTES = 65536     # o CSV vive no flash interno: sem limite, enche
nivel_de_objeto_na_linha = "nivel_de_objeto"
PING_MS = 2000            # heartbeat do nivel do sensor na serial (0 desliga)

pin = Pin(PRESENCE_PIN, Pin.IN, Pin.PULL_UP)
out = Pin(CAPTURE_OUT_PIN, Pin.OUT, value=0)
_candidatos = {n: Pin(n, Pin.IN, Pin.PULL_UP) for n in PINOS_CANDIDATOS}


def niveis_candidatos():
    return " ".join("p%s=%s" % (n, p.value()) for n, p in sorted(_candidatos.items()))


_niveis_ant = {}          # preenchido por instantaneo_pinos(), apos o armamento


def instantaneo_pinos():
    """Fotografa os pinos monitorados.

    Chamado depois do armamento: fotografar no import deixava invisivel qualquer
    mudanca de fio durante o aquecimento e o armamento (~1,5 s), o que contradiz
    a propria promessa de "descobrir a fiacao sem janela de tempo".
    """
    for n, p in _candidatos.items():
        _niveis_ant[n] = p.value()


def checar_mudanca_de_pino():
    """Loga mudanca em qualquer pino medido -- descobre fiacao sem janela de tempo."""
    for n, p in sorted(_candidatos.items()):
        v = p.value()
        antes = _niveis_ant.get(n)
        if antes is None:
            _niveis_ant[n] = v          # primeiro ciclo: so' baseline
            continue
        if v != antes:
            print("EV PINO_CHANGE p%s=%s antes=%s" % (n, v, antes))
            _niveis_ant[n] = v
_log = None
nivel_anterior = None


def log(evento, **campos):
    global _log
    partes = " ".join("%s=%s" % (k, v) for k, v in campos.items())
    print("EV %s %s" % (evento, partes))
    if _log is not None:
        try:
            if _log.tell() > LOG_MAX_BYTES:
                print("EV LOG_FAIL motivo=cheio limite=%d (log desativado)" % LOG_MAX_BYTES)
                _log.close()
                _log = None
                return
            _log.write("%d,%s,%s\n" % (time.ticks_ms(), evento, partes))
            _log.flush()
        except Exception as exc:
            avisar_falha_de_log(exc)


def abrir_log():
    global _log
    try:
        _log = open(LOG_PATH, "a")
    except Exception as exc:
        _log = None
        # falha silenciosa de log era o defeito: sem isto, o firmware prometia CSV
        # e nunca produzia, sem nenhum sinal na serial
        print("EV LOG_FAIL motivo=open erro=%s" % exc)


def avisar_falha_de_log(exc):
    global _log
    print("EV LOG_FAIL motivo=write erro=%s (log desativado)" % exc)
    _log = None


def main():
    global nivel_anterior
    abrir_log()
    log("READY", pin=PRESENCE_PIN, out=CAPTURE_OUT_PIN, debounce_ms=DEBOUNCE_MS,
        stable=STABLE_READS, miss=MISS_READS, guard_ms=GUARD_MS, warmup_ms=WARMUP_MS,
        arm_ms=ARM_MS)
    print("EV PINOS %s (sensor deve ser o que responder ao objeto)" % niveis_candidatos())

    # aquecimento: descarta o transitorio de boot
    t_fim = time.ticks_add(time.ticks_ms(), WARMUP_MS)
    while time.ticks_diff(t_fim, time.ticks_ms()) > 0:
        time.sleep_ms(DEBOUNCE_MS)
    log("WARMUP_DONE", nivel=pin.value())

    # arma SOMENTE quando a linha fica estavel em REPOUSO (nivel 1) por ARM_MS.
    # Sem timeout: enquanto houver algo na frente do sensor (ou o sinal estiver preso em LOW), o
    # firmware avisa e NAO arma. O heartbeat continua saindo aqui: sem ele, um sensor morto ou mal
    # ligado deixava o no' mudo e o texto do aviso culpava o objeto (o codigo nao pode saber a causa).
    repouso_desde = None
    t_armado = None
    t_ping = time.ticks_add(time.ticks_ms(), PING_MS)
    proximo_aviso = time.ticks_add(time.ticks_ms(), 3000)
    while True:
        if pin.value() == 1:
            agora = time.ticks_ms()
            if repouso_desde is None:
                repouso_desde = agora
            if time.ticks_diff(agora, repouso_desde) >= ARM_MS:
                t_armado = repouso_desde
                break
        else:
            repouso_desde = None
            if time.ticks_diff(proximo_aviso, time.ticks_ms()) <= 0:
                log("ARM_WAIT", nivel=pin.value(), nota=nivel_de_objeto_na_linha)
                proximo_aviso = time.ticks_add(time.ticks_ms(), 5000)
        if PING_MS and time.ticks_diff(time.ticks_ms(), t_ping) >= 0:
            print("EV PING nivel=%s fase=armando %s" % (pin.value(), niveis_candidatos()))
            t_ping = time.ticks_add(time.ticks_ms(), PING_MS)
        time.sleep_ms(DEBOUNCE_MS)
    # nivel=1 e' a condicao que armou (o laco so sai com a linha em repouso):
    # reler o pino aqui podia publicar nivel=0, contradizendo o proprio armamento
    log("ARMED", nivel=1, repouso_ms=ARM_MS)
    instantaneo_pinos()

    hits = 0
    misses = 0
    aberta = False
    n = 0
    t_abertura = 0
    # inicio_repouso = primeiro instante do periodo CONTIGUO em que o sensor esta livre;
    # None = o sensor nao esta livre agora (presenca confirmada). Nova janela exige um
    # periodo livre contiguo >= GUARD_MS imediatamente antes da presenca.
    # Sentinelas: 0 e' invalida sob ticks_diff (uptime entre ~6,2 e ~12,4 dias da negativo).
    inicio_repouso = t_armado if t_armado is not None else time.ticks_ms()
    suprimidas = 0
    suprimido_ativo = False

    while True:
        nivel = pin.value()

        # debounce primeiro: LEVEL so' e' publicado quando a amostra crua ja tem
        # STABLE_READS/MISS_READS concordando (antes, um glitch de 20 ms publicava
        # "estado=objeto" sem nenhuma janela)
        if nivel == 0:
            hits += 1
            misses = 0
            confirmado = hits >= STABLE_READS
        else:
            misses += 1
            hits = 0
            confirmado = misses >= MISS_READS

        if confirmado and nivel != nivel_anterior:
            log("LEVEL", nivel=nivel, estado=("objeto" if nivel == 0 else "repouso"),
                amostras=(hits if nivel == 0 else misses))
            nivel_anterior = nivel

        agora = time.ticks_ms()
        if confirmado and nivel == 0:
            # presenca confirmada: o periodo livre terminou (isto e' o que faltava:
            # sem reiniciar o cronometro, uma presenca continua acabava satisfazendo a guarda)
            livre_ms = 0 if inicio_repouso is None else time.ticks_diff(agora, inicio_repouso)
            inicio_repouso = None
            if not aberta:
                if livre_ms < GUARD_MS:
                    suprimidas += 1
                    # uma linha por PRESENCA suprimida, nao uma a cada 100 ms: com o
                    # objeto parado na frente saiam ~50 linhas iguais enchendo o CSV
                    if not suprimido_ativo:
                        log("SUPPRESSED", n=n, motivo="guarda", suprimidas=suprimidas,
                            resta_ms=GUARD_MS - livre_ms)
                        suprimido_ativo = True
                    hits = 0
                else:
                    aberta = True
                    hits = 0
                    n += 1
                    t_abertura = agora
                    out.value(1)
                    log("OPEN", n=n, nivel=nivel, t_ms=agora, livre_ms=livre_ms)
                    suprimido_ativo = False
        elif confirmado and nivel == 1:
            if aberta:
                aberta = False
                misses = 0
                dur = time.ticks_diff(agora, t_abertura)
                out.value(0)
                # o pulso de saida dura o tempo da presenca do item
                log("CLOSE", n=n, nivel=nivel, dur_ms=dur, guard_ms=GUARD_MS)
                inicio_repouso = agora      # comeca o periodo livre
            elif inicio_repouso is None:
                inicio_repouso = agora      # sensor voltou a ficar livre
                suprimido_ativo = False

        checar_mudanca_de_pino()

        if PING_MS and time.ticks_diff(time.ticks_ms(), t_ping) >= 0:
            print("EV PING nivel=%s n=%s aberta=%s %s"
                  % (nivel, n, aberta, niveis_candidatos()))
            t_ping = time.ticks_add(time.ticks_ms(), PING_MS)

        time.sleep_ms(DEBOUNCE_MS)


main()

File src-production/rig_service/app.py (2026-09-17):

#!/usr/bin/env python3
"""Servico de rig: captura das tres cameras, serie e manifest.

Expoe as rotas consumidas pelo gateway (`api.py`): /estado, /dataset-series, /historico,
/teste-trigger-3-cameras, /configurar-delay, /capturar-3-cameras e /series-3-cameras/<serie>.
Grava a serie em PNAAT_SERIES_DIR com manifest.json e os JPEGs das cameras (csi, usb, espcam).
A ponte serial e chamada por PNAAT_PONTE.

    python3 app.py [--porta 8090]
"""
from __future__ import annotations

import argparse
import base64
import contextlib
import json
import os
from io import BytesIO


# --- ROI por camera (derivada das caixas anotadas; ver dataset/TRABALHO/roi_por_camera.py)
ROI_POR_CAMERA = {}


def _carrega_roi() -> dict:
    from pathlib import Path as _Path          # import tardio: no topo do modulo Path pode nao existir
    try:
        dados = json.loads(_Path(os.environ.get('PNAAT_ROI_JSON', '/opt/pnaat-vision/roi.json')).read_text())
        return {cam: v.get('roi_normalizada') for cam, v in (dados.get('cameras') or {}).items()
                if v.get('roi_normalizada')}
    except Exception as exc:  # sem roi.json o pipeline segue com a imagem inteira
        print(f'[roi] sem configuracao ({exc}); seguindo com frame inteiro')
        return {}


def _recorta_roi(destino: Path, camera: str) -> None:
    """Recorta a ROI da camera no arquivo ja gravado (roda depois da rotacao)."""
    caixa = ROI_POR_CAMERA.get(camera)
    if not caixa:
        return
    try:
        from PIL import Image
        with Image.open(destino) as im:
            largura, altura = im.size
            x = int(caixa['x'] * largura)
            y = int(caixa['y'] * altura)
            w = int(caixa['w'] * largura)
            h = int(caixa['h'] * altura)
            if w > 16 and h > 16 and (w < largura or h < altura):
                im.crop((x, y, x + w, y + h)).save(destino, format='JPEG', quality=95, subsampling=0)
    except Exception as exc:
        print(f'[roi] falha ao recortar {camera}: {exc}')


_ROI_CARREGADA = False


def _camera_do_nome(destino: Path):
    """A câmera vem do nome do arquivo; só JPEG entra (json passa direto)."""
    if destino.suffix.lower() not in ('.jpg', '.jpeg'):
        return None
    nome = destino.name.lower()
    for marca, camera in (('acerola-csi', 'csi'), ('acerola-usb', 'usb'),
                          ('espcam', 'espcam'), ('foto-', 'csi')):
        if marca in nome:
            return camera
    return None


def _aplica_roi_no_arquivo(destino: Path) -> None:
    """Recorta a ROI da câmera no arquivo já gravado (depois da rotação)."""
    global _ROI_CARREGADA
    if not _ROI_CARREGADA:
        ROI_POR_CAMERA.update(_carrega_roi())
        _ROI_CARREGADA = True
    camera = _camera_do_nome(destino)
    if not camera:
        return
    caixa = ROI_POR_CAMERA.get(camera)
    if not caixa:
        return
    try:
        from PIL import Image
        with Image.open(destino) as im:
            largura, altura = im.size
            x, y = int(caixa['x'] * largura), int(caixa['y'] * altura)
            w, h = int(caixa['w'] * largura), int(caixa['h'] * altura)
            if w <= 16 or h <= 16 or (w >= largura and h >= altura):
                return
            recorte = im.crop((x, y, x + w, y + h))
        temporario = destino.with_name(destino.name + '.roi.tmp')
        recorte.save(temporario, format='JPEG', quality=95, subsampling=0)
        temporario.replace(destino)
    except Exception as exc:
        print(f'[roi] falha em {destino.name}: {exc}')
import subprocess
import threading
from pathlib import Path
import time
from http.server import BaseHTTPRequestHandler, ThreadingHTTPServer
from urllib.parse import parse_qs, urlparse

from PIL import Image, ImageDraw

import visao

DIR = visao.DIR
DADOS = visao.DADOS
HISTORICO = DADOS / "historico.jsonl"
_cam: visao.Camera | None = None
_trava = threading.Lock()
_ultimo: dict = {"veredito": None}
ESP_CAM_FRAME_URL = os.environ.get("PNAAT_PONTE", "http://127.0.0.1:8094").rstrip("/") + "/frame.jpg"
USB_CAMERA_DEVICE = "/dev/video8"


def _usb_device() -> str:
    """Acha a webcam pelo nome do driver; o número /dev/videoN muda entre boots."""
    for nome in sorted(Path('/sys/class/video4linux').glob('video*/name')):
        try:
            texto = nome.read_text().strip().lower()
        except OSError:
            continue
        if 'webcam' in texto or 'usb camera' in texto or 'generalplus' in texto:
            return '/dev/' + nome.parent.name
    return USB_CAMERA_DEVICE
SERIES_DIR = Path(os.environ.get("PNAAT_SERIES_DIR", "series-3-cameras")).resolve()
# em producao declare PNAAT_SERIES_DIR com o diretorio real das series; sem env, o default e relativo
# ao cwd (o teste de rotas e os fluxos sem hardware usam esse default e sobrescrevem antes de rodar)
ROTACAO_USB = 90    # webcam montada girada: 90 graus anti-horario corrige
ROTACAO_ESP = 180   # sensor do ESP-CAM montado invertido
TRIGGER_DIR = DADOS / "triggers"
PREVIEW_DIR = Path(os.environ.get('PNAAT_RIG_PREVIEW', '/dev/shm/pnaat-dataset-preview'))

# Modelo neural local: o site continua dono da camera; este worker consulta a API
# em :8093 e publica a ultima imagem anotada sem disputar /dev/video.
MODELO_API = os.getenv("PNAAT_MODEL_API", "http://127.0.0.1:8093")
MODELOS_VISTA = {"lateral": "v0-lateral.pt", "topo": "v0-top.pt"}
MODELO_NOME = os.getenv("PNAAT_MODEL_NAME", MODELOS_VISTA["lateral"])
MODELO_VISTA = "topo" if MODELO_NOME == MODELOS_VISTA["topo"] else "lateral"
MODELO_CONF = float(os.getenv("PNAAT_MODEL_CONF", "0.25"))
_modelo_lock = threading.Lock()
_modelo = {"status": "inicializando", "vista": MODELO_VISTA, "modelo": MODELO_NOME, "deteccoes": [],
           "inference_ms": None, "atualizado_em": None, "jpeg": None, "veredito": None, "erro": None}
_modelo_thread: threading.Thread | None = None
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

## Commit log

2026-09-08 docs: "adiciona RF-01.1 (barreira por oclusao + ESP32) e RF-30 (estroboscopio RGB)"
    Adiciona o requisito RF-01.1 (detecção de garrafas via barreira oclusiva retrorrefletiva 3M e tratamento no ESP32) e o RF-30 (iluminação estroboscópica RGB sincronizada via trigger).
2026-09-08 docs: "adiciona RNF-21 referente a lente difusora para mitigacao de hotspots"
    Inclui o RNF-21, especificando o uso de lente difusora óptica em PLA 3D/acrílico para eliminar hotspots (pontos estourados de luz) nas garrafas PET/Vidro.
2026-09-08 docs: "atualiza HW-04 com iluminacao estroboscopica RGB e lente difusora 3D"
    Atualiza a ficha HW-04 detalhando o arranjo físico dos 2x LEDs RGB de 5 mm, uso de difusores e alinhamento do sensor E18-D80NK a 10°–15° com fita 3M.
2026-09-08 docs: "registra D-18 para estroboscopio RGB e D-19 para desacoplamento ESP32/RPi5""
    Registra as decisões de projeto D-18 (sistema de iluminação estroboscópica RGB com difusor) e D-19 (desacoplamento de tarefas em tempo real via ESP32).
2026-09-08 docs: "atualiza diagrama Mermaid com fluxo ESP32 e LEDs"
    Atualiza o diagrama em Mermaid na arquitetura para incluir o subbloco de tempo real no ESP32 (tratando o sensor E18-D80NK com fita 3M, o VL53L0X e o encoder KY-040), o acionamento PWM do estroboscópi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
2026-09-08 Aprimora descrição do RF-01.1 no documento funcional
    Atualiza o comportamento do trigger E18-D80NK para incluir detalhes sobre a detecção de garrafas e a validação com o VL53L0X.
2026-09-08 Alinhar escopo e metodologia de iluminação com RF-30 e RNF-21
    Updated descriptions for test bench, cameras, and lighting methodology to include additional details on components and configurations.
2026-09-09 Adicionar pontos em aberto de validação do gatilho E18-D80NK e do difusor
    Updated evaluation and validation details for various items in the architecture documentation.
2026-09-09 Registrar fonte do trigger e saturação de pixels no schema do hub
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2026-09-10 feat(cad): commitar modelo R05 coluna v6 em trabalho
    Modelo 3D em desenvolvimento (optical-rig-r05-column-v6.fcstd) com a
    composicao da coluna modular Pi5 + case vertical + grip C-clamp
    substituindo o light-clamp. Inclui os scripts FreeCAD que o geram
    (bloco optico, cabos, validacao, bootstrap) para os integrantes
    conseguirem reproduzir e continuar o refinamento.
    [optical-rig-r05-column-v6.fcstd]
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2026-09-10 feat(cad): entregar exports v6 + report bloco optico para o time
    - Visualizacao: STL (renderiza no GitHub) + STEP (importa em qualquer CAD)
    exportados via freecadcmd headless da montagem v6 (40 shapes).
    - Edicao: FCStd ja commitado em 72376ea; scripts do bloco optico
    ajustados pelo agente (bootstrap/block/finish/validate) para reproducao.
    - Report R05-OPTICAL-BLOCK: restricao do cabo 200mm, gates G1/G4 PASS,
    G2/G3/G5/G6 FAIL por MCP timeout — estado parcial entregue ao time.
    [optical-rig-r05-c-clamp.step, optical-rig-r05-column-v6.step, optical-rig-r05-column-v6.stl]
2026-09-10 fix(cad): corrigir STEP v6 vazio + persistir bloco optico recuperado
    - STEP v6 anterior (1640B, commitado em b80218e) era vazio: Part.export
    falha silenciosamente neste freecadcmd. Regenerado com Import.export:
    40 shapes, 10.3MB validos.
    - Persistir R05OpticalBlock reconstruido apos reboot/PC travado: FCStd
    106 objetos (37.7MB) + STEP das 12 pecas impressas (6.7MB) + 5 vistas.
    - gates detalhados no report R05-OPTICAL-BLOCK.md (G1/G4 PASS;
    G2/G3/G5/G6 FAIL por MCP timeout na validacao).
    [optical-rig-r05-column-v6.step, optical-rig-r05-optical-block-printed.step]
2026-09-10 chore(cad): subir exports R05 completos + docs reference
    - Exporta para o time todas as iteracoes R05: coluna v2/v3/v4/modules,
    v5 (FCStd), bloco optico (printed STL 12 pecas + assembly STL),
    refined previews, validations v3/v5/v6, screenshots v3/v5.
    - Remove lixo de debug (t_single*, FCBak, preview redundante) e
    refined.fcstd corrompido (não sobe quebrado).
    - Docs reference de defect inspection (EfficientDet + PySource).
    [R05Refs-v3-BLOCKED.FCStd, optical-rig-r05-column-draft.step, optical-rig-r05-column-modules-v2.step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]
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2026-09-10 feat(cad): rig 2 cameras obtusas com g-clamp 1/4-20
    Design novo ancorado na analise optica R05 (b1d8859f):
    - 2x CM3 Wide em lados opostos: esquerda-baixa (Y-171, Z43) +
    direita-alta (Y+171, Z302), cada uma com a lateral inteira da
    garrafa 2L (H345) a elevacao ~49deg, deixo ~171mm (cabo 200 OK).
    - G-Clamp na base com rosca 1/4-20 UNC (padrao de tripe, modelo
    joehann fully printable + tripod): preso a esteira/pc, rosca no
    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
    [optical-rig-r05-twocam-gclamp.FCStd, optical-rig-r05-twocam-gclamp.stl]
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2026-09-10 feat(cad): analise optica 2 cameras + deep research approach CAD
    - R05-CAMERA-DISTANCE-ANALYSIS: distancia de foco p/ garrafas <=2L com
    2x CM3 Wide em lados opostos (E>=49, deixo ~171mm, dentro cabo 200mm).
    Correcao: camera lateral inteira (nao meia garrafa) e lente -Z local.
    - DEEP-RESEARCH-CAD-APPROACH: relatorio independente — build123d+OCP
    recomendado, OpenSCAD rejeitado (sem STEP B-Rep), FreeCADCmd so p/
    FCStd, OTG: export+reopen+fingerprint == sucesso.
    - twocam-gclamp FCStd: orientacao das cameras corrigida (lente aponta
    para a garrafa, dot=1.0).
    [optical-rig-r05-twocam-gclamp.FCStd]
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2026-09-11 ingest(ref): inventario de pecas DIN rail para o rig R05
    Levantamento das pecas comerciais/imprimiveis que substituem a coluna
    impressa (o que travava as iteracoes):
    - #1 case Pi5 DIN (Diyalec, CC BY-SA) — adotada
    - #2 bracket trilho->M6 (ADSRMedia, CC BY-NC-SA) — fixacao na esteira
    - #3 adaptador de angulo 90 deslizante (Shroamer) — traversa perpendicular
    que corre nas verticais
    - #4 DIN Rail Bracket Redux (herr_brain) — clip parametrico com parametros
    documentados (closed_width 34mm, spring 1.6mm, furos 51mm)
    - #5 gerador parametrico FreeCAD de bracket DIN (grbl.org)
    - #6 Adafruit 4557 (comercial)
    Inclui norma TS35/EN 50022/IEC 60715 e sintese do que ja esta pronto vs
    o que so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
2026-09-11 ingest(ref): baixar DIN Rail Bracket Redux (clip DIN parametrico)
    5 variantes .3mf validadas (zip + 3dmodel.model):
    - din-clip-redux (60x18x8mm), heatset, heatset-42mm, reverse, selftap
    Medidas conferidas por parsing dos vertices do mesh.
    Metodo: API GraphQL publica do Printables (campo stls { id name }) para os
    IDs, + URL do CDN media.printables.com derivada dos pares fileId_uuid da
    pagina renderizada. SHA256SUMS no diretorio.
    Nao baixados (bloqueio): angle adapter (Shroamer, .step sem thumbnail ->
    par fileId_uuid nao exposto; 144 combinacoes testadas, 404) e bracket M6
    (ADSRMedia). Registrado em raw/PROVENANCE.md.
2026-09-11 ingest(ref): baixar angle adapter (90 deslizante) e bracket M6
    - angle-adapter/: 4 STEP (73/100/120/150mm) medidos via FreeCAD
    (37 x 12 x comprimento; 7 solids cada) + PDF do autor.
    Peca-chave: monta SOBRE o trilho vertical a 90 graus e desliza ->
    travessa perpendicular com ajuste de altura.
    - m6-bracket/: 3 STL (screw-through + keyhole L/R, 26 x 39 x 11.5mm) +
    PDF. Interface trilho -> furacao M6 para fixar na esteira.
    - PROVENANCE atualizado com bbox medidos; SHA256SUMS nos diretorios.
    - Licencas: angle adapter UNVERIFIED_FROM_PRIMARY; M6 CC BY-NC-SA 4.0.
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2026-09-11 feat(cad): mount da camera CM3 Wide p/ trilho DIN (v1)
    Primeira versao da unica peca do rig que precisou ser projetada. Base =
    clip DIN do 'DIN Rail Bracket Redux' importado (nao redesenhado) + berco
    da camera fundido (49 graus).
    8 gates medidos (nao presumidos), todos PASS:
    - solido unico valido (10376 mm3), envelope 60.0x27.4x35.5 (K1C ok)
    - canal DIN 34.2mm na base -> 32.0 na ponta (chanfro; autor=34mm)
    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
    [camera-mount-din-v1.step]
2026-09-11 fix(cad): mount v3 - integracao com a camera validada (0 interferencia)
    O teste de integracao (montar a camera no mount e medir interferencia)
    pegou 6 erros reais acumulados; v3 corrige todos:
    1. berco no lado errado do clip (solids=2) -> face de montagem Z=0
    2. gate de angulo com eixo errado (41 vs 49) -> vertical = Y local
    3. gate do canal por vertices (32) -> 34.2mm medido por rasterizacao
    4. camera afundada na placa (487mm3 de interferencia na PCB) ->
    apoia pela face FRONTAL: offset DZ = BED_T + 0.75
    5. furo da lente raso (a lente de 8mm saia do furo) -> passante 24mm
    6. nervura de fusao bloqueava o furo da lente -> cortes por ultimo
    Resultado v3 (medido):
    - integracao PASS: PCB 0.0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
    [camera-mount-din-v3.step]
2026-09-11 chore: untrack midia, exports e vendor (mantidos fora do repo)
    [R05Refs-v3-BLOCKED.FCStd, camera-mount-din-v1.step, camera-mount-din-v3.step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]
2026-09-11 feat(cad): mount v6 validado com o modelo COMPLETO da camera (0.043 mm3)
    Validacao com o STEP oficial do CM3 Wide (631 solidos):
    interferencia 0.0434 mm3 (limite 0.1) -> PASS. 1 solido, 8787 mm3,
    bbox 60.0 x 27.7 x 35.8 (K1C ok), canal DIN 34.2->32.0mm, angulo 49.0.
    7 defeitos reais encontrados pelos testes ao longo das versoes:
    1. berco no lado errado do clip (solids=2)
    2. camera apoiada pela face errada (487mm3)
    3. furo da lente raso (445mm3)
    4. nervura bloqueando o furo (ordem de operacoes)
    5. parede x conector FPC de 23mm (112.96mm3)
    6. furo Ø13 nao cobre a carcaca da lente 18x11mm (100.03mm3)
    7. pinos raspando nos furos ambiguos do STEP (2.2 -> 0.04mm3)
    Decisoes: recesso retangular 1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
    [camera-mount-din-v6.step]
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2026-09-11 Revert "feat(cad): vistas do mount v6 (mount + camera + trilho) para revisao"
    This reverts commit 4b77e645b87888f104d93aee6a056ae121f15344.
2026-09-11 chore: Remove detailed requirement documents for data interfaces, actuation and safety, hardware and machine learning, operation, and overall requirements. Update evidence documentation to clarify me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
    [camera-mount-din-v6.step]
2026-09-11 fix(dataset): devolve dataset/ (81 frames do rig) ao versionamento
    O untrack de midia (10/09) levou junto o dataset inteiro: 81 frames que estavam
    versionadas desde o commit fa22164. Voltam com 1,86 MB e sha256 identico a copia
    canonica em datasets/pnaat/origem/.
    A excecao de midia passa a cobrir imagens dentro de dataset/ (gate e .gitignore);
    video, CAD e qualquer midia fora de dataset/ seguem bloqueados.
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2026-09-11 docs(cad): consolidar workspace CAD — indices, relatorios, validacoes e scripts
    - Indice, revisao de modelos, relatorios (Astra, checklist adversarial v1/v2, plano de impressao), TRANSFER + manifesto.
    - reports/: 34 laudos de referencia (otica/rig, envelopes, G0 da esteira, decisao MDF/FDM) com os sidecars .sha256 intactos.
    - Auditorias: r07 (build/verify/closeout, SHA256SUMS.json recalculado apos a sanitizacao), base-estrutura v1/v2, composicao completa/corrigida, portico de montantes, validacao Astra.
    - scripts/ (FreeCAD headless + validadores CadQuery) e data/g0 + data/concepts (templates e contratos liberados).
    - Higiene de publicacao por sanitizar_repo.py: hostnames, caminhos pessoais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
2026-09-11 fix(cad): parametrizar caminhos de host nos scripts de bancada e nas ferramentas de agente
    - 13 scripts FreeCAD/CadQuery: o caminho absoluto da bancada virou os.path.expanduser("~"); os dois run.sh usam $HOME; a docstring do repro-montagem descreve o host de bancada, nao o host nominal.
    - auditar_referencias.py: --state-db/--pastes/--vault passam a vir do argumento ou do ambiente (PNAAT_BANCO_SESSOES, PNAAT_PASTES_ORIGEM, PNAAT_VAULT) e o relatorio fala em banco de sessoes.
    - classificar_rest.py: credenciais lidas de PNAAT_AGENTE_AUTH (auth_path()).
    - classificar_gemini.py: a lib do agente vem de PNAAT_AGENTE_LIB; o diretorio de dados e herdado do host.
    - Mudanca de contrato declarada: as tr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
2026-09-11 Create video pitch script in Roteiro.tex
    This document outlines the script for a video pitch, detailing the problem, proposed solution, demonstration, and conclusion. It includes a time distribution for each section to ensure the presentation fits within the allocated time.
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2026-09-12 docs(arquitetura): alinha diagrama e componentes com emenda D-23 - Atualizado fluxo do nucleo para exibir 'classificacao por dominio' - Corrigida definicao de funcoes do multi-view (laterais vs topo)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
2026-09-12 docs(referencias): corrige ano do Eng. Proc. para 2022 e marca o sensor A*STAR como nao verificavel
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2026-09-12 feat(iamralp): captura multi-view com verificacao de posicionamento fail-closed (NCC + tolerancia em px)
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2026-09-14 fix(esp32cam): fecha lacunas achadas na revisao do commit anterior
    Revisao do 280f202 encontrou 3 achados materiais e 1 de observabilidade:
    - **gate incompleto**: a suite do firmware nao era coletada (o gate chama `pytest`
    dentro de `code-workspace`), entao os testes de transporte nunca rodavam em
    verificacao automatica. Agora o gate roda as duas suites: 96 + 15;
    - **escrita fora do mutex**: `ESP_LOGI` do driver da camera escreve no UART por
    fora do `log_printf` e podia intercalar DENTRO de uma mensagem binaria, alem de
    somar ~0,5 kB de ruido por foto. `esp_log_level_set("*", ESP_LOG_WARN)` silencia
    INFO de componente; medido no mesmo cenario: 0 linhas de componente no painel e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
2026-09-15 fix(site): atualiza html do site para iniciar molde de novo design
2026-09-15 feat(site): implementa redesign dos componentes do dashboard
    atualiza os painéis de operação, capturas, investigação, qualidade, saúde da Pi e relatório de lote, adicionando nova hierarquia visual, cards, estados, hovers e melhorias de navegação.
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2026-09-15 fix(site/api): fecha travessia de evidencia, traduz id de cartao e tira rotulos sem dado
2026-09-15 fix(site): auditoria de ponta a ponta - lote real, contagem por vista, qualidade e botoes funcionais
2026-09-15 fix(dataset): pipeline de deteccao com validade verificavel
    - base limpa: pre-treino so com dados externos (pesos anteriores tinham visto o teste)
    - k-fold por item corrigido: listas separadas, dir unico por execucao, assert de disjuncao
    - quase-duplicata por hash perceptual antes do split (sha256 sozinho nao protegia)
    - 4a classe corpo_deformidade e classe deformidade deixa de ser descartada em silencio
    - resolve() para midia do Label Studio; gate de classe adaptativo por vista
    - avaliacao por limiar por classe e evidencia visual (mosaico + JSON por imagem)
    - receita reproduzivel + filas em dataset/TRABALHO/filas/; relatorio do dia em docs/reference/
    - caminhos por ambiente/relativos ao rep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
2026-09-15 fix(site/api): revisao paralela por feature - laco da investigacao, filtro de vista, contrato de erro e dado inventado
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2026-09-15 feat(dataset): guardiao de recursos para treino + fila serializada + auditoria adversarial
    Motivo: o servidor de treino travou sob treinos concorrentes (load ~9 numa maquina de 8 threads).
    A convencao do repo ja dizia uma GPU/rodada; passou a ser imposto por script.
    - filas/guardiao_treino.sh: gate de RAM/swap/load/disco/GPU, watchdog de 60s, nice/ionice,
    limite de threads e log de estado (a evidencia que faltou no incidente)
    - filas/fila_v7seq.sh: cadeia SEM treino paralelo (build -> treino -> avaliacao -> proximo)
    - auditoria_adversarial.py: checagens que podem falhar (vazamento entre base e teste, disjuncao
    do k-fold, dado da equipe no dataset, contagens vs instancias, escopo dos com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
2026-09-15 feat(dataset): teste de inferencia ao vivo na camera (bancada) + resultado
    - dataset/TRABALHO/inferencia_camera_teste.py: le --camera ou --url (MJPEG), aplica limiar por
    classe + regra do silencio, salva quadros e resumo
    - teste real: 351 quadros, latencia mediana 5,9 ms, ZERO alarme falso, confianca maxima 0,109
    em cena desconhecida (nao alucina fora do dominio)
    - achado: cena vazia precisa ser estado proprio (sem peca), distinto de peca presente e incerta
    - leitura feita pelo MJPEG do servico que ja detem o V4L2 (nao abri o device: nao interferi)
2026-09-15 fix(debug): rotas estado/gatilho devolvem os campos direto (painel ficava vazio); registra o gatilho fechando a serie de 3
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2026-09-15 fix(dataset): correcoes de metodo (limiar na val, metrica por camera) + site de teste
    - limiar estava sendo escolhido NO TESTE: refeito na val -> 0,40 e F1 0,571 no teste
    (o 0,711 anterior estava inflado ~0,14 pela selecao no teste)
    - val tem 11 imagens: selecao de limiar precisa do k-fold (pendencia declarada, nao numero)
    - metrica por camera: espcam 0,650 x usb 0,333 -> a USB perde as 4 tampa_ausente
    - site_teste_camera.py: pagina de bancada (MJPEG anotado + decisao ao vivo, limiar por classe)
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2026-09-15 fix(dataset): revisao do fluxo de treino e pre-processamento
    - ACHADO GRAVE: treino recorta a ROI, deploy nao. medido a 416px: F1 macro 0,590 (crop) vs
    0,417 (quadro inteiro); defeito_tampa 0,471 -> 0,091 com 17 falsos positivos
    - trocar imgsz invalida o limiar: a 480 @0,15 = 0,711; a 416 o MESMO limiar = 0,590
    - treino-v1-args.yaml declarava 320/60; o que produziu os numeros foi 480/150 (alinhado)
    - captura nao trava exposicao/ganho/WB; fallback de ROI e fail-open (degradacao silenciosa)
    - mede_descasamento_roi.py: mede o custo do descasamento em vez de supor
2026-09-15 fix(delay): atraso por camera visivel e verificavel no site (configurado x medido), manifesto parcial e ressincronia da ponte
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2026-09-15 fix(site): rotulo de erro vazio diz nenhum e excecao crua vira linguagem clara; D-45 registra a revisao ponta a ponta
2026-09-15 fix(dataset): exportador descobre projetos no banco + calibracao de limiar na val
    - ACHADO: a lista fixa de projetos deixou o projeto 22 (143 anotacoes, dado novo da
    equipe) fora do export. O export saiu com 236 linhas em vez de 379 e a cadeia inteira
    treinaria com dado velho, calada. Mesma classe do achado da ROI: copia local onde
    deveria haver fonte unica.
    - agora descobre os projetos COM anotacao no banco do Label Studio (somente leitura),
    com fallback explicito e aviso alto
    - calibra_limiar_val.py: escolhe o limiar por classe NA VALIDACAO (protocolo correto) e
    grava no contrato de pre-processamento com a flag de calibrado
    - fila_v8.sh: cadeia completa (export->montagem->treino-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
2026-09-15 fix(site): gravacao de delay sem camera escolhida e recusada, resultado visivel e seletor explicito (D-48)
2026-09-15 fix(dataset): politica de decisao por defeito-nao-detectado, nao por F1
    - caso real investigado: defeito detectado a 0,201, limiar calibrado por F1 era 0,25 -> escapou
    como normal (na camera USB, a mais fraca, coerente com a metrica por camera)
    - com defeito_tampa em 0,15: NENHUM dos 5 defeitos do teste passa como normal
    custo medido: 4 alarmes falsos em 27 imagens (aceitavel: vira conferencia)
    - vies de seguranca na regra (classe de defeito acima do limiar vence normal) mantido como defesa
    - contrato: limiar 0,15 + objetivo declarado; o 0,25 fica registrado como otimo-de-F1 (nao usar)
2026-09-15 docs(incidente): queda do host do rig sem causa provada, journal persistente, kiosk com autostart e dois defeitos de pos-boot corrigidos (D-49)
2026-09-15 fix(dataset): site de teste consome o contrato (era o ultimo consumidor com tabela propria)
    Revisao de fim de cadeia achou a MESMA classe de defeito tres vezes no mesmo dia: copia
    local onde deveria haver fonte unica.
    - pacote v8a dizia defeito_tampa 0,25 e o contrato 0,15 -> pacote passa a derivar do contrato
    - pacote v8a estava sem LEIA-ME (o v7a tinha) -> instrucoes de deploy + preflight restauradas
    - site de teste tinha limiares proprios -> agora le o contrato
    - site subia em 416 (nao calibrado) e o leitor de limiares pegava a chave booleana de
    calibracao (bool e int em Python), devolvendo um dict sem limiar nenhum -> default 480,
    filtro apenas das classes e recusa explicita de imgs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
2026-09-15 fix(site): formulario de delay sobrevive a repintura automatica (listener + MutationObserver); D-50 registra a causa do eu- pus-e-nao-foi
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2026-09-15 feat(dataset): blur calibrado na nitidez real das cameras + correcao de rotulos na montagem
    - MEDIDO (var Laplaciano nas imagens de teste): espcam 377,6 · usb 155,1 · rig 14,7 -> os casos
    borrados sao 25x mais macios que a ESP-CAM. O aumento tinha so GaussianBlur(0.4-1.0) a p=0,3.
    - agora: gaussiana 1-3 (p 0,20) · gaussiana 4-7 (p 0,15) · movimento 5-11px (p 0,17) · leve (p 0,10)
    severidade amostrada na faixa real; fotometrico, nao toca rotulo
    - montador: rotulos passam a ser transformados para o espaco do RECORTE (antes ficavam no espaco
    do quadro inteiro -> caixas deslocadas; medido: defeito_tampa F1 0,400 -> 0,923 com a correcao)
    - guardiao: swap alto sozinho nao aborta mais (e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
2026-09-15 fix(ponte): ACK de baud falha-fechado — valor corrompido nao troca o UART para 46 baud
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2026-09-16 feat(src-production): integra o site ao pacote e endurece o runtime
    - site/: move para src-production/site/ e ajusta o default de --site em api.py
    - api: bind em loopback por padrao; token obrigatorio fora dele e 401 em POST sem bearer
    - frontend: escape comum de HTML/URL e token via fragmento (sessionStorage), sem token em URL
    - ingestao: recusa sobrescrever evidencia ja registrada (bytes diferentes no mesmo destino)
    - registro: BEGIN IMMEDIATE em corrigir() com transacao fechada em toda saida de erro
    - transporte binario: END validado (evento, seq, payload, CRC) e chunk limitado ao total_len
    - higiene: literais de caminho pessoal viram variavel de ambiente no classificador e nos scorers
    -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
2026-09-16 fix(src-production): fecha a revisao adversarial do site integrado
    - api: erro de configuracao (token obrigatorio fora do loopback) sai como mensagem
    declarada com codigo 2, nao como traceback
    - frontend: canario de token entra na suite (fragmento -> sessionStorage -> header,
    e nenhuma montagem de token em query string), rodando node via pytest
    - testes: variavel morta removida no teste de ingestao
    - formatacao: linhas longas dos caminhos por ambiente reformatadas
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2026-09-16 feat(cad): versiona o cad-produto como entregavel do CAD
    Entra a pasta revisada com os binarios, porque o STL e o produto que se quer
    imprimir. Sao 21 pecas do portico, a montagem de referencia, as pecas de impressao,
    as referencias e a atribuicao de terceiros em ATRIBUICOES.md.
    Os arquivos do entregavel resolvem caminho por __file__ e por variavel de ambiente,
    sem caminho pessoal nem hostname. O manifest e o SHA256SUMS acompanham e sao a
    condicao da excecao de midia.
    [A_BRACKET.stl, A_CLAMP.stl, A_PECA.stl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]
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2026-09-16 feat(src-production): integra a revisao do produto, o pipeline de treino e o indice de modelos
    [INDEX.csv]
2026-09-16 fix(repo): tira o link externo do versionamento, estreita as excecoes do CAD e alinha a documentacao de dependencias e bypass
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2026-09-16 fix(src-production): declara o banco do teste de serie homonima
2026-09-16 fix(repo): tira do indice o link para a area externa de referencias
2026-09-16 fix(gate): numera os seis passos de forma consistente
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2026-09-17 Entrega final: produto, firmware de trigger, servico de rig e documentacao ponta a ponta
    src-production (produto, treino, firmware esp32cam + trigger node, rig_service, site, testes); docs (guia de operacao, replicacao, arquitetura, hardware, CAD); esquematico Wokwi do trigger; docker (a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
    [REORGANIZACAO-20260916.csv]
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
